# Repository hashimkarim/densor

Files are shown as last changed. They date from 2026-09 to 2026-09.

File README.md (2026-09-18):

# Densor



## About the project

Densor is an intraoral sensor platform, attached to regular dental retainers or aligners, that can take measurements inside the mouth. 

## Rationale

At present, in mouth measurements are typically made with external tools and in a controlled labaratory setting. Thus, real data from users daily lives is missing. To overcome this, we propose using widely used deltal retainers (or aligners), and enhance them with the Densor sensing platform. This way data is collected from inside the mouth without external tools. 

## Features

1. **Contactless transmission:** Densor is completely sealed and interacts with a smartphone via [NFC protocol](https://en.wikipedia.org/wiki/Near-field_communication). 
2. **Energy harvesting:** To stay powered Densor harvests energy, either from the [NFC communication itself](https://github.com/TUDSSL/densor/tree/master/NFC_harvester_battery_free) or from the [temperature gradient between the body and cold water](https://github.com/TUDSSL/densor/tree/master/TEG_harvester_battery_free). 
4. **Free of external hardware:** Operating Densor does not require any specialized tools, other than a NFC-compatible smartphone.

## Project layout

For the current NFC firmware (R2/R3 multirate logging), Android app, build
commands and protocol documentation, see the [software guide](NFC_harvester_battery_free/software/README.md).

This repository contains the design (both hardware and software) of two versions of Densor, based on the source of energy harvesting. Each version of the project is contained in its own folder:

1. **[Densor with NFC-based energy harvesting from a smartphone](https://github.com/TUDSSL/densor/tree/master/NFC_harvester_battery_free)**, as presented in [this research article](https://dl.acm.org/doi/10.1145/3699746);
2. **[Densor with thermoelectric energy harvesting from drinking cold water](https://github.com/TUDSSL/densor/tree/master/TEG_harvester_battery_free)**.

 

## Copyright

Copyright (C) 2024 TU Delft Embedded Systems Group/[Sustainable Systems Laboratory](https://github.com/TUDSSL).

MIT License or otherwise specified. See [license](https://github.com/TUDSSL/densor/blob/master/LICENSE.txt) file for details.

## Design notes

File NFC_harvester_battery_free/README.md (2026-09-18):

# Densor with NFC-based Energy Harvesting from a Smartphone

For the current R1/R2/R3 software, use the [firmware and Android guide](software/README.md).
The memory diagram and Time Sync/Charge operating steps below describe the
original published firmware. R2/R3 use independent sensor periods and the
Stop/Apply workflow documented in the current guide.



This is the official public repository for intraoral sensing platform, called Densor (a portmanteau of a word _dental_ and _sensor_), based on [NFC protocol](https://en.wikipedia.org/wiki/Near-field_communication) for energy harvesting and communication from a NFC-enabled smartphone. For a Densor version with thermoelectric energy harvesting from drinking cold water please refer to [this repository](https://github.com/TUDSSL/densor/tree/master/TEG_harvester_battery_free). 

## About the Project

This repository contains the design files of the NFC-based Densor:

- [Densor hardware](https://github.com/TUDSSL/densor/tree/master/NFC_harvester_battery_free/hardware)
- [Densor firmware](https://github.com/TUDSSL/densor/tree/master/NFC_harvester_battery_free/software/DentalSensor_StorageProject)
- [Android app](https://github.com/TUDSSL/densor/tree/master/NFC_harvester_battery_free/software/source_ST25NFCApplication_V3_9)
- [Experiment setup and data collected from Densor evaluation](https://github.com/TUDSSL/densor/tree/master/NFC_harvester_battery_free/data/experiments) presented in Densor's [accompanying publciation](https://dl.acm.org/doi/10.1145/3699746).

## Rationale behind Densor

Intraoral sensors are another type of sensors in the field of healthcare and technology. While head-worn wearables have made significant advancements in monitoring various health metrics, placing sensors directly in the mouth remains a challenge. Currently, we rely heavily on external tools to gather dental and oral health data, which leaves critical information missing. For those looking to deploy in-mouth sensors, the process is daunting, requiring them to start from scratch. Additionally, there is no straightforward way to keep these sensors small, safe, and capable of long-lasting communication, making it difficult to integrate them into practical applications.

## Challenges

Intraoral sensing is unique because it operates within one of the most dynamic and challenging environments in the human body—the mouth. Unlike other forms of wearable technology, intraoral sensors must contend with constant exposure to saliva, varying temperatures, and the mechanical forces of chewing and speaking. These sensors need to be not only highly sensitive and accurate but also biocompatible and safe for long-term use. Additionally, they offer the potential to gather real-time data on oral health, dietary habits, and even health conditions, providing insights that are difficult to obtain through external sensors. This makes intraoral sensing a powerful tool with unique capabilities that go beyond existing methods.

## Densor Architecture



### Communication and Data Storage

Densor uses the NFC interface (based on STMicroelectronics' [ST25DV64K](https://www.st.com/en/nfc/st25dv64k.html) NFC/RFID tag IC) for communication with a smartphone, and the on board non-voltatile memory to store measurements. This way, data collected by Densor is always available to be read out by the smartphone.

### Energy Harvesting

Energy is harvested from the NFC tag itself, and stored for later use. This allows for Densor's continous operation and reader-independent data collection.

### Energy Storage

The harvested energy is stored on capacitors instead of batteries. This makes Densor a battery-free device and thus safer and more acceptable than Densor based on batteries.

### Power Control

Despite using low-power sensors, energy would be drained from the storage capacitor(s) rapidly if Densor is kept continuously powered. As the harvested energy stored on the capacitors is limited, it is imperative that we save and expend this power carefully. To overcome this, we use a low power Real-Time Clock (RTC) [AB1805](https://abracon.com/Precisiontiming/AB18X5-RTC.pdf) with power switch for power management. This means that the microcontroller unit (MCU) and sensors are completely powered off in the inter-sample period, with only the RTC powered to determine wake up time. This method achieves better power saving than deep-sleep or any of the low power run modes of the MCU.

### Densor On-Board Sensors

As of now, Densor includes three sensing modalities: temperature, accelaration and light intensity. Measuring oral temperature, jaw position, and whether the mouth is open using intraoral sensors is useful for gaining insight into oral and overall health. Oral temperature sensors provide accurate readings to detect early signs of fever and inflammation. Jaw position sensors can monitor alignment and movement, making them valuable for detecting sleep patterns. Light sensors that detect whether the mouth is open can help track breathing patterns and oral habits, which are essential for identifying issues like mouth breathing or sleep-related disorders.

## Densor Operation



The above image shows examples of data collected by Densor and demonstrates its capabilities. The temperature can be seen rising to body temperature when Densor is inserted in the mouth. The light level falls when the mouth is closed, and rises when the mouth is open. It also varies when the user is speaking. When drinking cold water, the temperature initally falls and then rises back to body temperature.



Densor can also determine the orientation of the jaw when the head is tilted. This is particularly useful for measuring head position during sleep, as seen in the above figure. The figure shows actual data collected from a user during a full night's sleep with _one sample collected every two minutes_. We can see the orientation of the head change between left, right and center as the user changes their sleep position.

## Getting Started with Densor

The long-term goal of the Densor project is to lower the ceiling of development of intraoral sensors. Thus, we wish that everyone can build, use and even expand Densor to improve sensing capabilities and data collection. Here we explain the steps to create Densor from scratch.

### Building the Densor Hardware



The Densor printed circuit board (PCB) is built using off-the-shelf components and assembled onto a flexible PCB. In our case we have used the flex PCB services from [PCBway](https://www.pcbway.com/fpc-rigid-flex-pcb/flex-pcb.html). The picture above shows the main components of Densor ( (a comprehensive list of Densor hardware, along with links to buy them, can be found under [Hardware](https://github.com/TUDSSL/densor/tree/master/NFC_harvester_battery_free/hardware)).

- **A** Custom-designed PCB antenna
- **B** STMicroelectronics [ST25DV64K](https://www.st.com/en/nfc/st25dv64k.html) NFC tag
- **C** Seiko [CPH3225A](https://www.sii.co.jp/en/me/datasheets/chip-capacitor/cph3225a/) chip capacitor bank
- **D** Abracon [AB1805](https://abracon.com/Precisiontiming/AB18X5-RTC.pdf) RTC
- **E** STMicroelectronics [LIS2DW12](https://www.st.com/en/mems-and-sensors/lis2dw12.html) accelerometer
- **F** STMicroelectronics [STM32L021F4](https://www.st.com/en/microcontrollers-microprocessors/stm32l021f4.html) MCU
- **G** Vishay [VEMD1060X01](https://www.vishay.com/docs/84295/vemd1060x01.pdf) photodiode
- **H** Serial Wire Debug (SWD) programming port (which is cut off before embedding in a dental aligner).

The [Densor hardware](https://github.com/TUDSSL/densor/tree/master/NFC_harvester_battery_free/hardware) folder contains the [gerber files](https://github.com/TUDSSL/densor/tree/master/NFC_harvester_battery_free/hardware/gerbers_schematic) which can be used to order the PCBs directly. To order directly, use the `.gbr` Gerber output files and `.drl` drill file for manufacturing.



The hardware folder also contains Densor' [schematic](https://github.com/TUDSSL/densor/tree/master/NFC_harvester_battery_free/hardware/gerbers_schematic) and [KiCad](https://www.kicad.org/blog/2021/12/KiCad-6.0.0-Release/) project which can be used for further expansion or modifications of Densor. A screenshot of the Densor PCB design in KiCad can be seen above. To open the project using Kicad, launch Kicad and navigate to 'File' -> 'Open project' -> And choose the [`densor_nfc_v2.kicad_pro`](https://github.com/TUDSSL/densor/blob/master/NFC_harvester_battery_free/hardware/Densor_kicad_project/densor_nfc_v2.kicad_pro) project file. The project includes the KiCad project files `.kicad_pcb`, `.pro` and `.sch`.

With the PCB and components, we used the lead-free [SAC305](https://nl.mouser.com/datasheet/2/73/SMD291SNL250T3-595229.pdf) solder paste to assemble the Densor as per the schematic.

### Uploading the Firmware to Densor's MCU

Once the Densor hardware is assembled, the [STM32L021F4](https://www.st.com/en/microcontrollers-microprocessors/stm32l021f4.html) MCU on board the Densor needs to have the firmware uploaded. The Densor [software folder](https://github.com/TUDSSL/densor/tree/master/NFC_harvester_battery_free/software/DentalSensor_StorageProject) contains the [STM32CubeIDE](https://www.st.com/en/development-tools/stm32cubeide.html)-based project is required for this. The firmware is uploaded using a [J-Link Debug probe](https://www.segger.com/products/debug-probes/j-link/) and a 10-pin header.

_Note:_ The current version of the PCB also has an [5034800800 FPC connector](https://www.molex.com/en-us/products/part-detail/5034800800) with all SWD signals which can also be used for programming.

### Memory Layout and Pinout



### Using the Densor Smartphone App

With the firmware uploaded to the MCU, the Densor is ready to be uses. This can be verified with an Android-based smartphone running the Densor [smartphone app](https://github.com/TUDSSL/densor/tree/master/NFC_harvester_battery_free/software/source_ST25NFCApplication_V3_9). The app (screenshot below) is built using Android Studio and can interact with the assembled Densor PCB via NFC. Detailed instructions on how to build the app can be found [here](https://github.com/TUDSSL/densor/tree/master/NFC_harvester_battery_free/software/source_ST25NFCApplication_V3_9).



### Attaching Densor to Aligners using Epoxy

Finally, the Densor PCB has to be attached to the retiners or aligners. Clear plastic vaccum formed [retainers](https://en.wikipedia.org/wiki/Retainer_(orthodontics)) are widely used in orthodontic treatment. They can easily be fabricated with the help of a dental technician.

In our Densor fabrication process, first a [dental impression](https://en.wikipedia.org/wiki/Dental_impression) of each test subject was taken using [condensation silicone](https://products.coltene.com/EN/US/products/prosthetics/c-silicones/speedex/speedex-putty) placed on a dental impression tray. The hardened impression was later used to create a [plaster model](https://bredent-group.com/wp-content/uploads/2020/06/gipse-von-hoechster-Qualitaet_000727GB-20150601.pdf) of the subject's lower jaw teeth. Next, the plaster was placed inside an [Erkoform-3d+ dental  thermoforming unit](https://www.erkodent.de/en/product/?id=521210). Then, a dental [thermoforming plate](https://www.erkodent.de/wp-content/documents/products/thermoprosp_EN.pdf) was heated to 160 degrees Celcius by Erkoform-3d+, placed over the dental plaster and vacuum sealed. After vacuum sealing, all redundant and sharp edges of the fabricated aligner were removed by the cut-off wheel. The remaining imperfections were removed with the same cut-off wheel, and finally disinfected.

We used a [food safe epoxy](https://polyestershoppen.com/epoxy/voedselveilige-epoxy-419.html) to attach the assembled Densor PCB to the retainers. The epoxy has to be carefully mixed in a 10:6 ratio of resin and hardner, and applied over the PCB with a brush. The epoxy takes a _full five days to cure completely_ and must not be used before that even though it appears to have hardened.

**Once the epoxy is fully cured, Voila! You Densor is ready to use**.

## How to Operate Densor

To use Densor, begin with the smartphone app, and fully assembled Densor.

### Starting and Stopping Densor

_Step 1._ When you hold Densor close to the smartphone such that both NFC antennas of a Densor and a smartphone align, the app will launch automatically and Densor will begin charging.

_Step 2._ The capacitor's charged voltage will be displayed in the app. While Densor theoretically supports 3.3 V maximum capacitor voltage, in practice, it reaches about 2.6 V.

_Step 3._ To configure the on-board Densor sensors, go to the settings tab. Here, you can enable specific sensors, select the sampling rate, and set an optional delayed start. Click the `Update` button to apply these settings to the sensor.

_Step 4._ The Densor will only begin measuring once the time is synced. In the `Time Sync` tab, click the `Sync` button to start the sensor from the current time. The `Wipe` button deletes all previously collected data, while `Delete` resets the cursor without overwriting previous data with zeros.

_Step 5._ To stop the sensor, switch to `Charge` mode. This will revert the sensor to showing feedback on the charging voltage reached. _Note:_ This will also reset the timestamp. Please save measurements before putting Densor to charge mode.

### Reading the Data

_Step 1._ To save the data, go to the `Memory` tab and click `Dump memory to file`. In the 'Destination folder' field, enter your desired file name, then click `OK`. The data will be saved as a `.bin` file on your phone. The file is located in the 'Downloads' folder of the internal memory.

_Step 2._ To analyse this data, use the provided scripts avaible in the [data folder](https://github.com/TUDSSL/densor/tree/master/NFC_harvester_battery_free/data) of this repository.

_Step 3._ If the [experiment master](https://github.com/TUDSSL/densor/blob/master/NFC_harvester_battery_free/data/experiments/experiment_master_ui.py) script was used to generate the data as per a protocol, then place the generated `.bin` file in the [data dumps folder](https://github.com/TUDSSL/densor/tree/master/NFC_harvester_battery_free/data/experiments/data_dumps), and view the results with the [plot_labelled.py](https://github.com/TUDSSL/densor/blob/master/NFC_harvester_battery_free/data/experiments/plot_labeled.py) script. Make sure to use the [environment](https://github.com/TUDSSL/densor/blob/master/NFC_harvester_battery_free/data/environment.yml) provided.

## Collecting New Data

Data collected using Densor can be labelled and stored using the scripts in the [data folder](https://github.com/TUDSSL/densor/tree/master/NFC_harvester_battery_free/data/experiments).

1. **Using a predefined experiment protocol:** You can use a set of [existing experiment protocols](https://github.com/TUDSSL/densor/tree/master/NFC_harvester_battery_free/data/experiments/experiment_protocols) or create a new `.json` file to decide the tasks that will be performed while labeling data collected by Densor.
2. **Executing an experiment:** Run the [`experiment_master_ui.py`](https://github.com/TUDSSL/densor/blob/master/NFC_harvester_battery_free/data/experiments/experiment_master_ui.py) file to launch the instructing script. Perform the actions as instructed by the script for the prescribed duration.



3. **Save the data:** Save the data using the smartphone app with the name prompted by the script to a `.bin` file and place it in the [data_dumps](https://github.com/TUDSSL/densor/tree/master/NFC_harvester_battery_free/data/experiments/data_dumps) folder.
4. **Label and view the data:** Run the `data_labeller.py` script to label the data for further machine learning tasks, or `plot_labelled.py` file to view the data.

## Frequently Asked Questions

**1. How long does it take to charge Densor?**

It takes approximately a minute to charge Densor using a smartphone. The exact charging time depends on how well the antennas of Densor and the smartphone align. The exact charging voltage of the capacitors can be read on the app for feedback.

**2. How long does Densor run when fully charged?**

Densor's lifetime depends on the sampling rate and number of capacitors used. For example, when using two capacitors and sampling once every two minutes Densor lasts for about 7 hours on a single charge. To increase the lifetime, more capacitors can be added. This will however change the charging behavior as well.

**3. Is Densor comfortable to wear?**

In our opinion, the experience of using Densor is no different than using retainers. Thus, if using retainers/aligners anyway, Densor should cause no additional discomfort beyond usinh the retainer.

**4. Will the mouth opening detection based on light intensity work when sleeping in the dark?**

Unfortunately, the mouth opening detection only works when there is sufficient ambient light. We are investigating ways to increase sensitivity for dark environments.

**5. Can I buy a Densor?**

Densor can be built with the design files in _this repository_. We desire Densor to be a free open source platform that can be rebuilt and expanded by everyone. If you wish to use (or expand) for your own research, please do not hesitate to contact us. We are happy to assist in reproduction efforts.

## How to Contribute to this Project

We look forward to your contributions, improvements, additions and changes. Please follow the standard [GitHub flow](https://docs.github.com/en/free-pro-team@latest/github/collaborating-with-issues-and-pull-requests/github-flow) for code contributions. In macro terms this means the following.

1. [Fork the `master` branch](https://docs.github.com/en/free-pro-team@latest/github/getting-started-with-github/fork-a-repo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)  of this repository; make sure that your fork will be [up to date](https://docs.github.com/en/free-pro-team@latest/github/getting-started-with-github/fork-a-repo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) with the latest `master` branch.
1. Create an issue [here](https://github.com/TUDSSL/densor/issues) with a new feature or a bug report.
1. Perform changes on your local branch and [push them to your forked clone](https://docs.github.com/en/free-pro-team@latest/github/collaborating-with-issues-and-pull-requests/merging-an-upstream-repository-into-your-fork).
1. Create a [pull request](https://docs.github.com/en/free-pro-team@latest/github/collaborating-with-issues-and-pull-requests/creating-a-pull-request) referencing the issue it covers and wait for our response.

### List of Known Issues

List of all known issues is listed in the [Issues](https://github.com/TUDSSL/densor/issues) list of this project. If you found a bug or you would like to enhance Densor with new functionalities: [please contribute](#How-to-Contribute-to-this-Project)! We look forward to your additions.

## How to Cite This Work

The results of this project have been published in a peer-reviewed academic publication (from which certain technical figures and text in this file originate). Details of the publication are as follows.

* **Authors and the project team:** [Vivian Dsouza](https://www.linkedin.com/in/dsouzavivian), [Jeffrey Pronk](https://www.linkedin.com/in/jeffrey-p-ba3225332), [Christian Peppelman](https://www.linkedin.com/in/peppelmanc), [Víctor Ignacio Madariaga](https://www.linkedin.com/in/vignaciomr), [Tatiana Pereira-Cenci](https://www.linkedin.com/in/tatiana-pereira-cenci-78813118/), [Bas Loomans](https://www.linkedin.com/in/bas-loomans-370ba11/), [Przemysław Pawełczak](http://www.pawelczak.net/)
* **Publication title:** _Densor: An Intraoral Battery-Free Sensing Platform_
* **Pulication venue:** [Proceedings of the ACM on Interactive, Mobile, Wearable and Ubiquitous Technologies, Volume 8, Issue 4, November 2024](https://dl.acm.org/toc/imwut/2024/8/4)
* **Link to publication:** https://dl.acm.org/doi/10.1145/3699746 (Open Access)

To cite this publication please use the following BiBTeX entry.

```
@article{dsouza:imwut:2024:densor,
  title = {Densor: An Intraoral Battery-Free Sensing Platform},
  author = {Vivian {Dsouza} and Jeffrey {Pronk} and Christian {Peppelman} and V\'{i}ctor Ignacio {Madariaga} and Tatiana {Pereira-Cenci} and Bas {Loomans} and Przemys{\l}aw {Pawe{\l}czak}},
  journal = {Proc. ACM Interact. Mob. Wearable Ubiquitous Technol.},
  volume = {8},
  number = {4},
  pages = {191:1--191:30},
  year = {2024},
  publisher = {ACM}
}
```

## Acknowledgements

We thank [Tofik Babayev](https://www.linkedin.com/in/tofik-babayev-36aa561a0) from [TofDent](https://www.tofdent.nl), The Hague, The Netherlands, for help in fabricating all versions of the Densor. We also thank [Giuseppe Deininger](https://www.linkedin.com/in/giuseppe-deininger-564a40153) and [Jakub Patałuch](https://www.linkedin.com/in/jakubpat) for contribution to the development of Densor at the initial states of the development. We also thank [Lennart Klaver](https://www.linkedin.com/in/lennart-klaver-19010945) for first attempts in designing intraoral sensor hardware, [Jasper de Winkel](https://www.linkedin.com/in/jdewinkel) for system design consulting and [Izabela Grudzińska](https://www.linkedin.com/in/grudzinskaizabela) for dentistry consulting and for the inspiration of this project. The study was partly funded by the [ORANGE-FORCE](https://www.nivel.nl/nl/project/orange-force-mond-en-tandheelkundige-zorg-voor-ouderen) project co-funded by the [PPP allowance](https://www.health-holland.com/public-private-partnerships) made available by [Health Holland](https://www.health-holland.com), [Top Sector Life Sciences and Health](https://www.academictransfer.com/en/employer/Health-Holland/).

 

## Copyright

Copyright (C) 2024 TU Delft Embedded Systems Group/[Sustainable Systems Laboratory](https://github.com/TUDSSL).

MIT License or otherwise specified. See [license](https://github.com/TUDSSL/densor/blob/master/LICENSE.txt) file for details.

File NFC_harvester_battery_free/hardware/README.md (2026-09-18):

# Densor - Hardware

The TMP119 and its 100 nF capacitor sit **14.5 mm beyond the original PCB edge**.
R2/R3 remain **100 kΩ**, C14 connects `V_MCU` to `PSW`, and ALERT is unconnected.
The neck enforces 0.15 mm tracks for `V_MCU`/SDA/SCL and 0.20 mm for `PSW`,
with no vias/components; the continuous back GND fill and repaired GND connection remain.

[Current schematic](gerbers_schematic/schematic_nfc_baterry_free_fpc.pdf) ·
[Gerbers and drills](gerbers_schematic/gerbers_fpc) ·
[PCB layout](exports/pcb.pdf) · [3D render](exports/3d-oblique.png) ·
[BOM](exports/bom.csv) · [Placements](exports/placement.csv)

The original CAD stackup is retained, including its recorded **1.6 mm** thickness.
`exports/densor_nfc_v2.step` contains the native stackup and components;
`exports/board-1.6mm.step` is the nominal board envelope. Actual flex construction
and bend radius are unspecified in the original. Model sources and licenses are in
`Densor_kicad_project/vendor/`.

Latest checks: zero unrouted connections and no new DRC/ERC/parity findings.
The 31 DRC, 19 ERC and 20 metadata findings are inherited. Final I²C, wake/sleep
and bent/epoxied fit measurements across 2.6–1.8 V remain pending.
The purchasing links below are historical; use the schematic BOM for current
values, and complete its missing MPN fields before ordering.

## About the project 

This repository contains the design of Densor: an intraoral, actively powered, battery-free platform featuring multi-modal sensors and an extended lifespan. The repository consists of all components that make Densor:
- [Hardware](https://github.com/TUDSSL/densor/tree/master/NFC_harvester_battery_free/hardware)
- [Densor Firmware](https://github.com/TUDSSL/densor/tree/master/NFC_harvester_battery_free/software/DentalSensor_StorageProject)
- [Android app](https://github.com/TUDSSL/densor/tree/master/NFC_harvester_battery_free/software/source_ST25NFCApplication_V3_9)
- [Experiment setup and data collected](https://github.com/TUDSSL/densor/tree/master/NFC_harvester_battery_free/data/experiments)

This folder contains all the harware design files.

## Folder layout

- [KiCad project](Densor_kicad_project/densor_nfc_v2.kicad_pro): current design, local symbols, footprints and all 25 component STEP models.
- [Datasheets](datasheets): component reference PDFs.
- [Gerbers and schematic](gerbers_schematic): current extension Gerbers, drills, job file and schematic PDF.
- [Exports](exports): PCB views, renders, assembly drawings, BOM, placements and STEP files.

## Historical baseline purchasing references

| Component | Qty | Purchased from |
|---|-----|---|
| Storage Capacitor | 2 | [link to buy](https://www.digikey.com/en/products/detail/seiko-instruments/CPH3225A/8692444) |
| Decoupling Capacitor 100nF | 6 | [link to buy](https://nl.farnell.com/en-NL/kemet/c0603x104m4ractu/cap-mlcc-0-1uf-16v-0603/dp/2904941?st=0603%200.1uf) |
| Zener Diode | 1 | [link to buy](https://nl.farnell.com/on-semiconductor/mm3z3v6c/zener-diode-0-2w-3-6v-sod-323f/dp/2824925?CMP=i-ddd7-00001003) |
| Schottky Diode | 1 | [link to buy](https://nl.farnell.com/nexperia/1ps76sb40-115/diode-schottky-sod323/dp/1349646?CMP=i-ddd7-00001003) |
| Photo Diode | 1 | [link to buy](https://nl.mouser.com/ProductDetail/Vishay-Semiconductors/VEMD1060X01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) |
| Debug header | 1 | [link to buy](https://nl.farnell.com/samtec/ftsh-105-01-l-d-k/connector-header-10pos-2row-1/dp/2856435?CMP=i-ddd7-00001003) |
| FPC connector | 1 | [link to buy](https://nl.mouser.com/ProductDetail/Molex/503480-0800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) |
| Pin Header 01x04 | 1 | [link to buy](https://nl.mouser.com/ProductDetail/Harwin/M20-9770446?qs=ulE8k0yEMYbCPpMPHeYh4w%3D%3D) |
| Resistor 100kohm | 3 | [link to buy](https://nl.farnell.com/vishay/crcw0603100kfkea/res-100k-1-0-1w-0603-thick-film/dp/1469649?st=0603%20100k) |
| Resistor 8Mohm | 1 | [link to buy](https://nl.farnell.com/vishay/crcw06038m06fkea/res-8m06-1-0-1w-0603-thick-film/dp/2138717) |
| NFC Tag - ST25DV04K-JFR6D3 | 1 | [link to buy](https://www.digikey.nl/en/products/detail/stmicroelectronics/ST25DV64K-JFR6D3/7312974) |
| RTC - AM1805 | 1 | [link to buy](https://nl.farnell.com/en-NL/abracon/ab1805-t3/real-time-clock-i2c-qfn-16/dp/2467703?st=ab1805) |
| MCU - STM32L021F3Ux | 1 | [link to buy](https://www.digikey.nl/en/products/detail/stmicroelectronics/STM32L021F4U6TR/6166967) |
| Accelerometer - LIS2DW12 | 1 | [link to buy](https://nl.farnell.com/en-NL/stmicroelectronics/lis2dw12tr/lga-12-i-mems-digital-o-p-motion/dp/2849615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) |
| SPDT - TS3A44159 | 1 | [link to buy](https://www.digikey.nl/en/products/detail/texas-instruments/TS3A44159RSVR/1909585) |
| Crystal | 1 | [link to buy](https://nl.farnell.com/en-NL/abracon/abs05w-32-768khz-j-2-t/crystal-32-768khz-4pf-smd-1-6/dp/2850126?st=abs05w) |
| Solder paste | - | [link to buy](https://www.digikey.nl/en/products/detail/chip-quik-inc/SMD291SNL50T3/5130160) |

## Copyright

 

Copyright (C) 2024 TU Delft Embedded Systems Group/Sustainable Systems Laboratory.

MIT Licence or otherwise specified. See [license](https://github.com/TUDSSL/ENGAGE/blob/master/LICENSE) file for details.

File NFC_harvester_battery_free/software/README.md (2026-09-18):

# Densor firmware and Android software

The current firmware implements independent sensor periods with two storage
layouts and two schedulers. R2 uses a shared EEPROM pool; R3 uses per-sensor
partitions. Suffix **a** selects a retained finite-state machine (FSM), and
suffix **b** selects RTC-time scheduling. All four use protocol version 5.
They are software-tested candidates; physical timing, energy and power-loss
validation remain pending.

| Revision | Storage | Scheduler | Build selector |
| --- | --- | --- | --- |
| R2a | Shared pool | Retained FSM | `REVISION=R2a` |
| R2b | Shared pool | RTC time | `REVISION=R2b` |
| R3a | Per-sensor partitions | Retained FSM | `REVISION=R3a` |
| R3b | Per-sensor partitions | RTC time | `REVISION=R3b` |

The Makefile defaults to **R3a**. Storage and scheduler are selected when
building firmware; the Android app detects them and cannot switch them.
One current app supports legacy recordings, R1, and all four R2/R3 variants.

- [Implementation and operation](docs/multirate-implementation.md): scheduling,
  storage, migration, configuration and recovery.
- [Protocol version 5](docs/multirate-protocol.md): EEPROM map, records,
  requests and retained state.
- [Validation and limitations](docs/multirate-validation.md): checks run against
  this checkout and remaining hardware work.
- [R1 reference](docs/r1-software.md) and [R1 protocol v3](docs/r1-protocol.md):
  historical common-period logging and compatibility details.

## Build and check

From the repository root, with GNU Make, Python 3 and the
`arm-none-eabi-gcc` toolchain on `PATH`:

```sh
make -C NFC_harvester_battery_free/software/DentalSensor_StorageProject -j4 REVISION=R2a
make -C NFC_harvester_battery_free/software/DentalSensor_StorageProject -j4 REVISION=R2b
make -C NFC_harvester_battery_free/software/DentalSensor_StorageProject -j4 REVISION=R3a
make -C NFC_harvester_battery_free/software/DentalSensor_StorageProject -j4 REVISION=R3b
```

Each variant has its own directory under
`DentalSensor_StorageProject/build/<storage>-<timing>/`, containing
`densor-<revision>-<storage>-<timing>.elf`, `.bin`, `.hex`, `.map` and
`-manifest.json`. For example, R2b produces
`build/shared-rtc/densor-r2b-shared-rtc.elf`. Compiler flags and stack-usage
reports are also retained. Switching variants does not require cleaning.
The equivalent selectors are `STORAGE=shared|partitioned` and `TIMING=fsm|rtc`;
conflicting revision/strategy choices fail.

Host checks additionally require Clang with address/undefined-behavior sanitizer
runtimes, `javac` and `java`:

```sh
python3 NFC_harvester_battery_free/software/tools/test_r1.py
python3 NFC_harvester_battery_free/software/tools/test_multirate.py
```

To package all four variants and the matching Android app, set `JAVA_HOME` to
JDK 17 and `ANDROID_HOME` to an SDK with Android 33, build-tools 35.0.0,
platform-tools and accepted licenses, then run:

```sh
python3 NFC_harvester_battery_free/software/tools/build_multirate.py
```

The helper also accepts `--java-home` and `--sdk`. It creates a scoped SDK view,
checks build selections, runs both host suites, and builds/tests the Android
variants. Output is in `software/build/multirate-candidate/`: firmware images,
the release APK, manifests, checksums and build/test logs. This command builds
an unpublished candidate; it does not install or flash a device.

The app identifies as `com.st.st25nfc`, version `3.11.0-multirate`, code 29,
minimum API 23 and target API 33. It retains the project's local debug signing
configuration. A successful build does not establish compatibility with a
previously deployed signing key or release readiness.

`build_r1.py` is historical: it expects R1 artifact paths and APK version 28.
The current Makefile has no `REVISION=R1` target; use `test_r1.py` to check the
retained R1 implementation and decoder.

## Start a recording

1. Save the existing EEPROM dump, build the selected revision, and follow the
   [SWD migration procedure](docs/multirate-implementation.md#migration-and-provisioning).
2. In the app, read the detected revision and state. For a running R2/R3 session,
   select **Stop and checkpoint recording**, refresh after a device wake, and
   wait for acknowledgement before exporting the final recording.
3. Select sensors, a base period and each enabled sensor's period. Periods are
   whole multiples of the base. For example, base 10 s with LIS2DW12 temperature,
   TMP119, photodiode and acceleration periods of 120/60/30/10 s gives
   multipliers 12/6/3/1. Startup delay is 0–59 minutes.
4. Select **Apply settings and reset log**. This replaces the previous session
   once the MCU accepts it. Pending settings remain distinct from active ones.
5. Read binary/CSV snapshots in Data, or Stop and await acknowledgement for a
   completed recording. Times are elapsed seconds; UTC is unavailable.

R1 uses its own apply/reset workflow without a Stop command. The original
firmware's Time Sync/Charge workflow does not apply to R1/R2/R3.

## Work without a board

Build `:app:assembleDebug` from
[`source_ST25NFCApplication_V3_9`](source_ST25NFCApplication_V3_9), open
**ST25 dbg → Debug mode**, and select a sample or import a raw EEPROM `.bin`.
The debug package `com.st.st25nfc.dbg` can coexist with the release app.
R2/R3 imports require the complete 512-, 2048- or 8192-byte EEPROM image.
Virtual memory supports decoding, settings requests and export; it does not
simulate firmware acknowledgements, acquisition or time progression.

The [Sampling lab](../visualization/sampling_lab/README.md) exports synthetic
R1/R2a/R2b/R3a/R3b EEPROM images. The
[EEPROM lab](../visualization/eeprom_lab/README.md) compares memory layouts.
These are test and visualization tools; synthetic rates do not establish
physical firmware sampling performance.

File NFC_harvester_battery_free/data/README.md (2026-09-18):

# Densor - Data 

## About the project 

This repository contains the design of Densor: an intraoral, actively powered, battery-free platform featuring multi-modal sensors and an extended lifespan. The repository consists of all components that make Densor:
- [Hardware](https://github.com/TUDSSL/densor/tree/master/NFC_harvester_battery_free/hardware)
- [Densor Firmware](https://github.com/TUDSSL/densor/tree/master/NFC_harvester_battery_free/software/DentalSensor_StorageProject)
- [Android app](https://github.com/TUDSSL/densor/tree/master/NFC_harvester_battery_free/software/source_ST25NFCApplication_V3_9)
- [Experiment setup and data collected](https://github.com/TUDSSL/densor/tree/master/NFC_harvester_battery_free/data/experiments)

This folder contains all the scripts to collect, process and analyse the data using Densor, as well as the data collected itself.

## Folder layout

- [Synthetic multirate dataset](synthetic_multirate/README.md): simulated acceleration, light, and two temperature channels at 100 Hz, with noise-free curves and event labels for sampling comparisons.

- [Charging:](https://github.com/TUDSSL/densor/tree/master/NFC_harvester_battery_free/data/charging)  contains the data traces of how densor charges with a smartphone. 
- [Earpiece:](https://github.com/TUDSSL/densor/tree/master/NFC_harvester_battery_free/data/earpiece) contains the scripts used to collect data from the ear piece for the experiments that compare Densor to a similar earable platform.
- [Experiments:](https://github.com/TUDSSL/densor/tree/master/NFC_harvester_battery_free/data/experiments) contains all scripts and data used for the machine learning experiments.
- [Retainer:](https://github.com/TUDSSL/densor/tree/master/NFC_harvester_battery_free/data/retainer) contains all scripts and data collected from the Densor that are not related to the machine learning experiments.

## Setting Up the Environment

To set up the Conda environment from the provided `.yml` file, follow these steps:

### 1. Ensure Conda is Installed

Make sure you have Conda installed on your system. If you don't have it installed, you can download and install it from the [official Anaconda website](https://www.anaconda.com/products/distribution) or by using [Miniconda](https://docs.conda.io/en/latest/miniconda.html) for a lighter version.

### 2. Clone the Repository

Clone this repository to your local machine if you haven't done so already:

```bash
git clone https://github.com/TUDSSL/densor.git
cd densor
```

### 3. Create the Environment from the .yml File

Use the following command to create a new environment from the environment.yml file:

```bash
conda env create -f environment.yml
```

### 4. Activating the environment

Use the following command to activate the environment:

```bash
conda activate densor
```

## Description of how figures in the paper were produced

1. **Figure 5: Charging characteristics:** Run the `plot_charging_traces.py' script

```bash
cd NFC_harvester_battery_free/data/charging/
python3 plot_charging_traces.py
```   

2. **Figure 6 (a,b,c): Power and Lifetime** Run the `math_model_life.py' script

Set the below variables to True, based on the desired output
```
PLOT_CAPS = True
PLOT_CURRENT = False
PLOT_START_VOLTAGE = False
```

```bash
cd NFC_harvester_battery_free/data/charging/
python3 math_model_life.py
```   

3. **Figure 7: Example data from all sensors** Run the `plot_pretty_manually.py` script

```bash
cd NFC_harvester_battery_free/data/retainer/
python3 plot_pretty_manually.py
```
4. **Figure 10: Distribution of temperature and light intensity** Run the `data_ml.py` script with variable `plot_box_plots = True`
   
```bash
cd NFC_harvester_battery_free/data/experiments
python3 data_ml.py
```
5. **Figure 11 (a,b,c): Data from Densor and Earable** Run the `plot_ear_mouth_example_trace.py' script with arguments as explained [here](https://github.com/TUDSSL/densor/tree/master/NFC_harvester_battery_free/data/experiments).
6. **Figure 12: ROC** Run the `data_ml.py` script with variable `plot_roc_curve = True`

```bash
cd NFC_harvester_battery_free/data/experiments
python3 data_ml.py
```
7. **Figure 13: Example data from sleep** Run the `plot_pretty_sleep_manually.py` script

```bash
cd NFC_harvester_battery_free/data/retainer/
python3 plot_pretty_sleep_manually.py
```

## Copyright

 

Copyright (C) 2024 TU Delft Embedded Systems Group/Sustainable Systems Laboratory.

MIT Licence or otherwise specified. See [license](https://github.com/TUDSSL/ENGAGE/blob/master/LICENSE) file for details.

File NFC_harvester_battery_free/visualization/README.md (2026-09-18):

# Densor visualization labs

Local browser tools for exploring Densor sampling and EEPROM storage.

| Lab | Purpose | Default port | Requirements |
| --- | --- | --- | --- |
| [Sampling lab](sampling_lab/README.md) | Explore sensor rates and export synthetic recordings. | 8765 | Bash and Python 3.10+ |
| [EEPROM lab](eeprom_lab/README.md) | Compare memory layouts and page crossings; vary payloads and add sensors. | 8767 | Bash, Node.js 22.18+ and npm |

From the repository root, start either lab:

```sh
./NFC_harvester_battery_free/visualization/sampling_lab/run.sh
./NFC_harvester_battery_free/visualization/eeprom_lab/run.sh
```

Each script also works from inside its lab folder as `./run.sh [port]`, or by
absolute path from any directory. For example, `./run.sh 9000` starts at port
9000. Without an argument, it starts at the default above. If the port is busy,
it tries successive ports until it can bind, then prints the URL and opens it
in your default browser. Valid ports are 1–65535. On a headless machine, open
the printed URL manually. Stop the server with Ctrl+C.

Both servers bind to `127.0.0.1`. The EEPROM launcher installs its locked npm
dependencies on first run if they are missing (requires network access).
The sampling lab reads the existing
[synthetic dataset](../data/synthetic_multirate/README.md); generate it first if
it is missing. Each lab's README describes its features and validation commands.

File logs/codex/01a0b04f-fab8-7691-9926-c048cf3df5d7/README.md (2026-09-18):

# Summary

This conversation was used to create synethic data. I want to do implement multirate sampling in both the firmware and the android app. This high frequency (100Hz) allows me to make data dumps for testing at will.

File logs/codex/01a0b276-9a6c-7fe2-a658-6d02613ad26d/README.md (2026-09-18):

# Summary

This conversation was used to add all the 3D models to KiCAD and export all the resulting files/renders/pdfs.

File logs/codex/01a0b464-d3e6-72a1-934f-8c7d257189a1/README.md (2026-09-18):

# Summary

This conversation was used to document the R1 firmware changes, including temperature-sensor selection, EEPROM alignment, data formats, build instructions and testing. It also updated the implementation handoff for one firmware codebase with separate storage and timing modules. The Android app was extended to detect and support R1, R2 (shared pool) and R3 (partitions), including both FSM and RTC timing variants for R2/R3 and import of synthetic EEPROM `.bin` dumps. The debug workflow was tested using Android Agent Lab and the Samsung S21 FE, including settings changes, read-back and dump import/export; physical sampling timing and NFC hardware behavior still require a Densor board.

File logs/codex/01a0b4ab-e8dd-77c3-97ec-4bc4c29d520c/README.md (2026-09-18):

# Summary

This conversation was used to add a debug mode to the Android app so I could test sampling-interval settings without a Densor board. It supports importing EEPROM `.bin` dumps, changing settings in simulated tag memory, verifying them by reading them back, and exporting and reopening the modified dumps. The workflow was tested on the Samsung S21 FE and 13 automated tests passed; actual sensor sampling timing still requires a Densor board.

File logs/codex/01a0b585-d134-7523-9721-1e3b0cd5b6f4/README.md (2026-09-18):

# Summary

This conversation documented the current R2a/R2b shared-pool and R3a/R3b
partitioned firmware, including FSM/RTC scheduling, protocol v5, build selection,
SWD migration, Stop/Apply operation, data exports and recovery limits. The old
software README was retained as a historical R1 reference and repository entry
points now link to the current guides.

All four incremental firmware build targets and both host test suites passed.
Hardware validation remains pending. See [conversation](conversation.md) and
[verification record](qa/verification.json). No firmware code was changed.

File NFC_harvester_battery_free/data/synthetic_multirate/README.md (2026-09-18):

# Synthetic multirate sampling dataset

A reproducible, simulated recording to replay as the input to a sampling
experiment. It contains **one three-axis accelerometer, one light sensor, and
two temperature sensors**: six measurement channels. These are synthetic
signals, not measurements from a person or calibrated Densor hardware.

The supplied recording lasts **30 minutes at 100 Hz** (180,000 rows). Each row
represents an instantaneous observation, 10 ms after the previous one. The
last timestamp is 1799.99 s; the recording interval is `[0, 1800)`.

## Files

- [dataset/samples.csv](dataset/samples.csv): noisy measurements for the scanner.
- [dataset/ground_truth.csv](dataset/ground_truth.csv): matching noise-free
  curves, for evaluation only. Both temperature columns are identical here.
- [dataset/events.csv](dataset/events.csv): event labels and parameters, for
  evaluation only. Intervals include their start and exclude their end.
- [dataset/metadata.json](dataset/metadata.json): seed, units, model assumptions,
  sources, and file checksums.
- [dataset/validation.json](dataset/validation.json): generated-data checks and
  measured noise statistics.
- [dataset/overview.png](dataset/overview.png): whole recording.
- [dataset/detail.png](dataset/detail.png): close-ups of jaw motion and the
  small difference between the temperature channels.

## Columns and noise

| Column | Meaning | Independent Gaussian noise, standard deviation |
|---|---|---:|
| `time_s` | Elapsed time in seconds | None |
| `accel_x_g` | X acceleration, including gravity, in g | 0.0020 g |
| `accel_y_g` | Y acceleration, including gravity, in g | 0.0024 g |
| `accel_z_g` | Z acceleration, including gravity, in g | 0.0022 g |
| `light_norm` | Normalized light intensity, 0–1 | 0.0030 |
| `temp_1_c` | Temperature sensor 1, degrees Celsius | 0.015 °C |
| `temp_2_c` | Temperature sensor 2, degrees Celsius | 0.020 °C |

The temperature sensors have the **same underlying temperature, response, and
calibration**. Only their independent noise differs. These noise levels are
chosen simulation parameters, not measured sensor specifications. Light is
dimensionless and is not a lux measurement or the Densor ADC output.

The six measurement channels have independent noise streams. Event generation
uses a separate stream, so changing the noise cannot move the events.

## Events and assumptions

The default schedule has 8 rhythmic jaw-movement bouts, 5 speaking bouts,
4 mouth-open intervals, 3 cool-drink events, and 5 posture transitions.
Onsets are randomized without consulting the 120-second sampling grid.
The first 30 seconds contain no activity events and can be used to inspect
noise and slow baseline variation.

- **Posture:** smooth changes to roll and pitch rotate the 1 g gravity vector.
  The new posture persists after the transition. The event interval labels
  the transition, not the entire subsequent held posture.
- **Rhythmic jaw movement:** smoothly enveloped 0.5–1.5 Hz motion, with a small
  second harmonic and different projections onto the three axes. These bouts
  do not force the mouth open or produce a light signal.
- **Speaking:** irregular light fluctuations and smaller jaw movements during
  the same labeled interval. Illumination is assumed sufficient.
- **Mouth opening:** a sustained light increase and small pitch change, with
  smoothed opening and closing edges.
- **Drinking:** a light/opening transient and a smooth temperature decrease,
  followed by recovery. Temperature recovery continues after drinking ends.
  `end_s` labels the drinking action; `response_end_s` marks the observed end
  of the modeled thermal response. Recovery is smoothly tapered to zero
  between five and six time constants.
- **Temperature baseline:** slow variation around 36.4 °C. Both temperature
  channels receive exactly the same baseline and drink response.

The jaw rhythm range is motivated by Martinot et al. (2021), who report
0.5–1.5 Hz mandibular movements in phasic sleep bruxism:
<https://pmc.ncbi.nlm.nih.gov/articles/PMC8397703/>.
Their chin-mounted inertial system differs from Densor. Chun et al. (2020)
demonstrate intraoral acceleration sensing at 54 Hz with four-second analysis
windows: <https://doi.org/10.1145/3410531.3414309>.
The Densor paper motivates the light/speaking and temperature/drinking
relationships: <https://doi.org/10.1145/3699746>.

Event durations, amplitudes, occurrence counts, noise levels, temperature
recovery constants, and 100 Hz reference rate are **simulation choices**.
The recording combines illustrative activities and is not a clinical sleep
recording, a validated physiological model, or evidence of detection accuracy.

## Scan or replay

The scanner should receive only `samples.csv`. At replay time `t`, expose the
newest row with `time_s <= t`. For real-time playback, release rows every
10 ms; for accelerated playback, advance the same simulation clock faster.
Use elapsed timestamps to determine availability rather than relying on the
precision of operating-system sleep calls.

For a sampler starting at zero, the suggested fixed rates align exactly with
the reference grid:

| Sampler | Rows selected, counting the first data row as index 0 |
|---|---|
| Original, all sensors every 120 s | 0, 12000, 24000, … |
| Accelerometer, 25 Hz | 0, 4, 8, …; read all three axes together |
| Light, 1 Hz | 0, 100, 200, … |
| Both temperatures, 0.1 Hz | 0, 1000, 2000, … |

These are point samples. Do not average the rows between observations unless
that is the acquisition behavior being evaluated. A held/interpolated output
is not an additional measurement. A 100 Hz reference is a discrete surrogate
for a continuous signal; it does not model unobserved content above 50 Hz,
sensor filtering, quantization, startup delay, energy, or storage constraints.

Keep `ground_truth.csv` and `events.csv` out of the scanner; use them afterward
to score detection and reconstruction. Repeat with multiple seeds and sampling
phases before drawing conclusions. The optional multirate settings here are
comparison settings, not validated optimal rates or a firmware implementation.

## Regenerate

With Python 3.11 or newer, from this directory:

```bash
python -m pip install -r requirements.txt
python generate.py
```

The default output is `dataset/` next to the generator. To make a separate
recording without overwriting the supplied one:

```bash
python generate.py --seed 42 --output /tmp/densor-synthetic-42
```

`--duration-s` (minimum 300 s) and `--rate-hz` (minimum 50 Hz) are configurable.
The seed defaults to 20260918. Identical parameters and NumPy version reproduce
the CSV files byte for byte. `validation.json` includes serialization,
temperature-noise independence, and event/quiet-region checks.

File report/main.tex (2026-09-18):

% Based on the supplied article template, with a compact report layout.
\documentclass[a4paper]{article}
\usepackage[a4paper,margin=15mm]{geometry}
\usepackage[T1]{fontenc}
\usepackage[default]{sourcesans}
\pdfmapfile{=SourceSansThree.map}
\usepackage{microtype}
\usepackage{graphicx}
\usepackage{xcolor}
\usepackage{titlesec}
\definecolor{ink}{HTML}{182535}
\definecolor{muted}{HTML}{526171}
\definecolor{linkblue}{HTML}{0866C6}
\definecolor{rulegray}{HTML}{D8E0E8}
\usepackage[colorlinks=true,allcolors=linkblue]{hyperref}
\pagestyle{empty}
\setlength{\parindent}{0pt}
\setlength{\parskip}{2pt}
\setlength{\emergencystretch}{2em}
\titleformat{\section}{\color{ink}\bfseries\fontsize{11.5}{13.5}\selectfont}{}{0pt}{}
\titlespacing*{\section}{0pt}{7pt}{3pt}
\hypersetup{
  pdftitle={PhD Assignment Report},
  pdfauthor={Hashim Karim},
  pdfsubject={Temperature sensor selection, placement, integration and firmware improvements}
}

\begin{document}
\color{ink}
\fontsize{10.2}{12.2}\selectfont
\begin{minipage}[t]{0.60\linewidth}
\vspace{0pt}
{\fontsize{25}{28}\selectfont\bfseries PhD Assignment Report\par}
\end{minipage}\hfill
\begin{minipage}[t]{0.38\linewidth}
\vspace{0pt}
\raggedleft
{\fontsize{11}{13}\selectfont\bfseries Hashim Karim\par}
{\fontsize{9.3}{12}\selectfont
\href{mailto:h.karim-2@student.tudelft.nl}{h.karim-2@student.tudelft.nl}\\
\href{https://github.com/hashimkarim/densor}{github.com/hashimkarim/densor}\par}
\end{minipage}
\par\vspace{5pt}
{\color{linkblue}\hrule height 0.8pt}
\vspace{2pt}

\section*{Approach}
I extended Densor with external temperature sensing and independent sampling
rates. Revision 1 (R1) corrects baseline logging; Revision 2 (R2) and
Revision 3 (R3) introduce shared and partitioned multirate storage, respectively.

\section*{Sensor selection}
I considered an NTC thermistor, MAX30208, TMP117 and TMP119 for the 2.6--1.8~V
supply, prioritizing energy per reading. An NTC would require an accuracy budget
covering the thermistor, reference resistor and ADC, and possibly calibration.
\href{https://www.analog.com/media/en/technical-documentation/data-sheets/max30208.pdf\#page=8}{MAX30208}
offered lower conversion current, but its longer possible result latency could
extend the device's active time. I chose \textbf{TMP119} for factory-calibrated
I\textsuperscript{2}C readings, conversion energy similar to TMP117, tighter
specified accuracy and better tolerance to assembly and bending stress.
Professional assembly made its small package practical.

\par\vspace{5pt}
\begin{minipage}[t]{0.53\linewidth}
\vspace{0pt}
\section*{Sensor placement}
I placed TMP119 14.5~mm beyond the original board edge, with its 100~nF decoupling
capacitor nearby. The extension is intended to allow placement farther back in
the mouth, away from the main electronics. Literature examples favoured posterior
sites for reduced airflow effects
(\href{https://doi.org/10.1038/s41405-022-00114-8}{de Almeida e Bueno et al., 2022})
and greater temperature stability
(\href{https://doi.org/10.1016/j.rineng.2025.105284}{Zhao and Bergmann, 2025}).
\end{minipage}\hfill
\begin{minipage}[t]{0.44\linewidth}
\vspace{0pt}
\centering
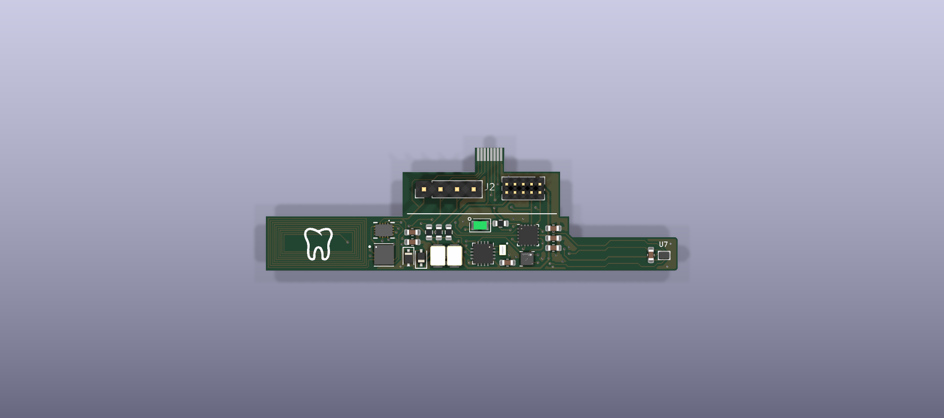
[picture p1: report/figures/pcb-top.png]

\par\vspace{3pt}
{\fontsize{8.5}{10}\selectfont\color{muted} Top-view PCB render. TMP119 (U7) sits at the right-hand tip of the extension.\par}
\end{minipage}

\section*{Firmware: temperature sensing and EEPROM logging}
At each RTC wake, firmware reads the sensors due, saves their data and powers
down. I added TMP119 \textbf{one-shot measurements without averaging} to shorten
active time: a conversion typically takes
\href{https://www.ti.com/lit/ds/symlink/tmp119.pdf\#page=14}{15.5~ms, versus 124~ms for eight averages}.
While TMP119 converts, firmware reads other due sensors, then collects its result
with a timeout. Users can select either temperature sensor or both; the log keeps
their readings separate, records supply voltage and reports missing sensors.

Extra EEPROM page writes cost energy. In R1, I moved the two-byte log pointer
from addresses 7--8 to 8--9 and aligned records to four-byte page boundaries.
This reduces avoidable page crossings at the cost of padding bytes. Firmware
checks that the record fits, waits for its writes to finish, then saves the new
pointer before powering off. If a write cannot be confirmed, it stops.

\section*{Firmware: multirate sampling}
Independent sampling rates allow frequent motion measurements without spending
energy on unnecessary temperature readings. The RTC wakes at the
\textbf{GCD} of the sensor periods; the finite-state machine (FSM) repeats after
their \textbf{LCM}. For temperature/photodiode/acceleration every 120/30/10~s,
the RTC wakes every 10~s: acceleration runs each tick, photodiode every 3 ticks
and temperature every 12 ticks. The cycle repeats after 12 ticks (120~s).
The FSM keeps its step in RTC RAM between MCU power cycles and advances after saving
the data.

\textbf{R2} stores samples together in shared memory; \textbf{R3} gives each
sensor its own region, sized in Android from record size and sampling rate and
fixed during a recording. Suffix \textbf{a} uses the retained FSM; \textbf{b}
calculates the sampling step from RTC time. Keeping the current write positions
in RTC RAM reduces EEPROM updates. Periodic EEPROM checkpoints save these positions
for recovery. Checksums help detect damaged records;
loss of timing stops the recording.

\section*{Android integration and visualization}
One Android app supports \textbf{R1, R2a, R2b, R3a and R3b}, with common-rate or
per-sensor settings. Settings take effect after firmware confirmation; checks
detect changes during NFC reads. Binary/CSV exports and temperature plots use
each sensor's sampling times.

I built \textbf{Sampling lab} to compare selected rates
against synthetic 100~Hz signals and export capacity-checked EEPROM images for
Android debug import. \textbf{EEPROM lab} compares records, padding, page crossings
and allocation across baseline/R1/R2/R3, with adjustable payloads and extra sensors
for packing experiments. These are simulations, not energy measurements.

Recorded checks include all four builds, firmware fault injection, 360 C-generated
images decoded in Java and 14 Android fixture tests on an S21 FE. Energy savings,
unaveraged temperature accuracy and physical power-loss behavior still require
board measurements.

\par\vspace{5pt}
{\color{rulegray}\hrule height 0.5pt}
\vspace{4pt}
{\fontsize{8.5}{10.5}\selectfont\color{muted}\textbf{AI usage.} I used AI for minor KiCad tasks (adding 3D
models and exporting files), literature review, repository documentation,
adapting the Android app to the
firmware using my open-source Android AI development tool,
\href{https://github.com/hashimkarim/android-agent-lab}{Android Agent Lab}, and
creating web apps to visualize EEPROM paging and sampling.\par}
\end{document}

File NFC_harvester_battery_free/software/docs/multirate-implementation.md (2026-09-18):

# R2/R3 implementation and operation

This guide describes the implemented protocol-v5 firmware in this checkout.
See the [software overview](../README.md) for builds, the
[byte protocol](multirate-protocol.md) for serialization, and
[validation record](multirate-validation.md) for evidence and open gates.

## Changes from R1

R1 samples all enabled channels on one common period and writes one padded
record per wake. R2/R3 retain independent LIS2DW12 and TMP119 temperature
selection, photodiode and acceleration, but give each stream its own period.
Both temperature sources can be enabled together, separately, or disabled;
at least one of the four streams must be enabled.

| Behavior | R1, protocol v3 | R2/R3, protocol v5 |
| --- | --- | --- |
| Acquisition | All enabled streams each wake | Only streams due on that base tick |
| Storage | Combined records from byte 128 | Shared pool or partitions from byte 168 |
| Integrity | Metadata CRC; raw pointer and records have no CRC | Record CRC8, paired pointer checkpoints, retained-state CRC16 |
| Scheduling | One period; no missed-wake reconstruction | Retained phase plus RTC checks; timing failures stop the session |
| Configuration | Apply/reset can replace a running session | Stop and acknowledge before Apply/reset |
| Progress | EEPROM pointer every successful wake | RTC RAM each tick; EEPROM checkpoints periodically and on close |

The protocol numbers and revision names are different concepts: R2a, R2b,
R3a and R3b all use version 5. Internal storage ID **1 is partitioned (R3)**
and **2 is shared (R2)**. The `DENSOR2!`/`DNR2` magic is common to both.

## Source organization

All variants share one board entry point and acquisition path in
[`densor_board.c`](../DentalSensor_StorageProject/Core/Src/densor_board.c).
[`densor_multirate.c`](../DentalSensor_StorageProject/Core/Src/densor_multirate.c)
owns metadata, configuration, retained state, checkpoints and recovery.
The Makefile links exactly one `densor_logger_shared.c` or
`densor_logger_partitioned.c`, and one `densor_scheduler_fsm.c` or
`densor_scheduler_rtc.c`. Common byte I/O and CRC16 helpers remain in
`densor_r1.c`; the TMP119 driver is `tmp119.c`.

The Android counterpart is
[`DensorMultirate.java`](../source_ST25NFCApplication_V3_9/app/src/main/java/com/st/st25nfc/densor/DensorMultirate.java).
It validates the same schedule, proposes partition sizes, creates requests,
decodes recordings and labels the detected revision. `DensorNfc.java` provides
verified NFC writes and metadata checks around reads.

## Scheduling and acquisition

The base period is an integer from 1 to 3540 seconds. Each enabled stream has
a positive 16-bit integer multiplier; disabled streams use zero. Its period is
`base × multiplier`, at most 2,592,000 seconds (30 days). The least common
multiple (LCM) of enabled multipliers must fit in 65,535 ticks.

Tick zero samples every enabled stream. Later ticks sample stream `i` when
`tick % multiplier[i] == 0`. With base 10 s and multipliers 12/6/3/1, all
streams sample at 0 s, only acceleration at 10 and 20 s, photodiode plus
acceleration at 30 s, and TMP119 joins them at 60 s. There is a wake on every
base tick, even if no stream is due; empty ticks advance the scheduler without
writing a record. Independent rates reduce acquisitions, but energy savings
must still be measured.

Both schedulers use the RTC calendar and 64 bytes of retained RTC RAM:

- **FSM (a):** selects streams from the retained phase modulo the LCM.
- **RTC time (b):** derives the tick from `(now − session_epoch) / base` and
  checks it against the retained next tick.

Both reject phase loss instead of backfilling missed measurements. Early or
duplicate wakes do not advance the schedule. Lateness tolerance is zero whole
seconds for a 1 s base and one second for a larger base; excessive lateness,
clock rollback or session duration beyond 30 days causes a phase error. These
are software rules, not measured timing guarantees. The RTC-time variant still
requires retained state and does not resume automatically after its loss.

After initializing the EEPROM, firmware rereads the RTC and sets the session
epoch to that reading plus the startup delay (0–59 minutes). Zero delay permits
the first sample on the accepting wake. The epoch is an RTC calendar count
from 2000-01-01, without a UTC synchronization guarantee. Exports use elapsed
seconds, not wall-clock timestamps. Scheduling strategy and crystal/RC oscillator
selection are separate settings; both strategies use the RTC to wake the MCU.

Only due channels are acquired. TMP119 uses bounded, unaveraged one-shots;
its conversion overlaps other sensor work. LIS2DW12 is configured for acquisition
when its temperature or acceleration is due. ADC supply measurement occurs
when a temperature or photodiode channel is due; acceleration-only wakes carry
an unavailable-supply marker. Sensor discovery and TMP119 shutdown still occur
on each boot, even when those channels are not due.

## Storage and full behavior

**R2 shared pool:** each nonempty tick appends a presence mask, supply code,
due payloads and CRC8, then zero-pads to a four-byte boundary. All channels
share the space from byte 168 to the physical capacity. The next complete
record must fit; there is no overwrite or circular buffer.

**R3 partitions:** each enabled stream has a fixed contiguous region. Scalar
records occupy four bytes; acceleration records occupy eight. Android allocates
at least one record to each enabled stream, then distributes remaining pages
in proportion to `record_size × (LCM / multiplier)`, assigning rounding leftovers
in stream order. Firmware validates and commits the supplied boundaries; it
does not calculate a different allocation. Boundaries stay fixed during a session.
The padding rule adds one zero byte only for an unpadded length congruent to
three modulo four; current scalar/acceleration records already need no padding.

Before acquisition, all records due on a tick are checked for available space.
If any would not fit, the whole session becomes FULL without acquiring that
tick. R3 therefore stops at the first limiting partition, even if other
partitions have room. The app previews allocation and expected capacity.

Each committed tick updates alternating retained-state copies. Durable EEPROM
pointer pairs are updated at `min(LCM, 64)`-tick intervals, LCM boundaries, and
Stop/full/error closure. This reduces routine pointer writes relative to R1.
Initialization fills checkpoint/data space with `0xFF`; CRC checks and schedule
validation distinguish records from the unused tail.

## Migration and provisioning

Changing R1 to R2/R3, or changing storage/timing variants, requires exporting
the old data and explicitly initializing the new format. Ordinary boot rejects
legacy, unknown or mismatched metadata without automatically formatting it.

1. Save and check the old full EEPROM binary before migration.
2. Build the intended revision using the [current Makefile commands](../README.md#build-and-check).
3. Use an independently powered bench board and its actual SWD probe. For
   example, this R3a command prepares a **dry run** from the repository root:

   ```sh
   python3 NFC_harvester_battery_free/software/tools/provision_r1.py \
     --protocol multirate \
     --elf NFC_harvester_battery_free/software/DentalSensor_StorageProject/build/partitioned-fsm/densor-r3a-partitioned-fsm.elf \
     --export saved-original.bin --interface interface/stlink.cfg
   ```

4. After verifying the export, ELF and probe selection, adding `--apply` flashes
   the MCU and destructively initializes metadata. The helper uses OpenOCD,
   breaks at `densor_boot_gate` after C initialization, and sets
   `densor_provision_request` to `0x44525035` for multirate firmware.
5. Read the tag with the current Android app and verify the expected R2/R3
   variant, physical capacity and empty STOPPED state before applying settings.

The helper's filename is historical; **`--protocol multirate` is required**.
Its default is R1, and it does not verify that the selected ELF matches that
protocol. The board also needs a valid RTC calendar; this helper does not set
or synchronize it. The physical provisioning sequence remains unvalidated.

## Configure, stop and export

The current app adapts its controls to the detected firmware. R2/R3 settings
show the base period, individual sensor periods, oscillator and startup delay.
The storage and timing strategies require a firmware change to replace.

For a running session, select **Stop and checkpoint recording**. It becomes
a pending request; refresh after the MCU's next wake and wait for STOPPED
with the request acknowledged. Export binary and/or CSV before choosing
**Apply settings and reset log**, which erases the previous recording on
acceptance. An outstanding request must be acknowledged before another is sent.
Stop does not power the board down indefinitely: stopped, full and error states
continue waking at the configured base period, or 120 s before configuration.
There is no extra command-polling loop. During startup delay, a request waits
until the scheduled wake.

Requests are CRC-protected and committed by a separate marker. Android shows
pending values without changing the active session. Firmware rejects Apply
while RUNNING and validates sensor availability and layout before starting the
new session. A valid but rejected request can close the session with an error;
inspect the reported state and acknowledgement rather than assuming success.

R2/R3 binary exports contain the entire physical EEPROM (512/2048/8192 bytes).
The decoder validates records and can scan a valid tail beyond the last EEPROM
checkpoint. Running reads are snapshots; metadata equality before/after a read
does not establish an atomic multi-stream acquisition snapshot. R3 recovery
may preserve different valid tails per stream after an interrupted wake.
Only STOPPED, error-free, acknowledged sessions are labelled complete.
Full/error exports are snapshots or recovered prefixes.

## Recovery and limits

Retained state has paired generations and an in-progress transaction flag.
Missing, ambiguous or interrupted state triggers a CRC-checked record scan
that verifies the durable checkpoint boundaries. A recoverable recording is
closed with a phase/recovery error; it is not silently resumed. A previously stopped recording remains
stopped after retained-state loss. Invalid pointers or corruption before a
checkpoint can prevent recovery entirely.

Configuration is not journaled as a whole. An interrupted CONFIGURING state or
damaged header/status can require saving a raw dump and reprovisioning. CRCs
detect many corruptions but are neither authentication nor proof of atomic
power-loss behavior. If EEPROM completion or a retained-state write is uncertain,
the board halts instead of deliberately cutting power and reacquiring. A bus
failure can also prevent recording the error in EEPROM.

TMP119 startup/shutdown costs, nonvolatile startup provisioning, real NFC
contention, runtime stack use and power-cut recovery still need bench tests.
See the [validation record](multirate-validation.md) before treating a candidate
as a measured hardware result.

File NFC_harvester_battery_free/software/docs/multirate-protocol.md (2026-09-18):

# R2/R3 byte protocol, version 5

This specification follows
[`densor_multirate.c`](../DentalSensor_StorageProject/Core/Src/densor_multirate.c),
the selected logger/scheduler modules and
[`DensorMultirate.java`](../source_ST25NFCApplication_V3_9/app/src/main/java/com/st/st25nfc/densor/DensorMultirate.java).
See the [operation guide](multirate-implementation.md) for lifecycle and recovery.
Integers are unsigned little-endian unless marked signed. Addresses and lengths
are bytes; region ends are exclusive. Structures are serialized explicitly.

## Identity and memory map

All four variants use `DENSOR2!`, header magic `DNR2` and format version 5.
Storage ID 1 means R3 partitions; ID 2 means R2 shared pool. Timing ID 1 means
FSM (suffix a); ID 2 means RTC time (suffix b). Firmware accepts only its
compiled storage/timing pair. Supported physical EEPROM sizes are 512, 2048
and 8192 bytes, checked against the device density at boot and on Android reads.

| Absolute address | Length | Contents / writer |
| --- | --- | --- |
| 0 | 8 | ASCII `DENSOR2!`; firmware format guard |
| 8 | 4 | Reserved zero; not an R1 pointer |
| 12 | 64 | Immutable session header; firmware |
| 76 | 16 | Status and acknowledgement; firmware |
| 92 | 40 | Pending `DCP5` request; Android |
| 132 | 4 | Request commit marker; Android |
| 136 | 32 | Four pairs of durable pointer slots; firmware |
| 168 | capacity − 168 | Record storage; firmware |

Metadata uses CRC-16/CCITT-FALSE (polynomial `0x1021`, initial `0xFFFF`, no
reflection or final XOR; `123456789` → `0x29B1`), stored LE16. Records and
pointer slots use CRC8 (polynomial `0x07`, initial zero, no reflection or final
XOR; `123456789` → `0xF4`). CRCs are integrity checks, not authentication.

## Header at 12

Offsets in this table are relative to the 64-byte header.

| Offset | Bytes | Meaning |
| --- | --- | --- |
| 0 | 4 | ASCII `DNR2` |
| 4 | 1 | Protocol version 5 |
| 5 | 1 | Storage: 1 partitioned, 2 shared |
| 6 | 1 | Header length 64 |
| 7 | 1 | Timing: 1 FSM, 2 RTC time |
| 8 | 2 | Physical EEPROM capacity |
| 10 | 2 | Log start 168 |
| 12 | 1 | Enabled sensor mask |
| 13 | 1 | Reserved zero; no common record stride |
| 14 | 1 | Oscillator: 0 external crystal, 1 internal RC |
| 15 | 1 | Supported sensor mask `0x0F` |
| 16 | 1 | Reserved zero |
| 17 | 1 | Sensors detected when configured |
| 18 | 1 | Startup delay, 0–59 minutes |
| 19 | 1 | Whole-second lateness tolerance: 0 for base 1, otherwise 1 |
| 20 | 4 | Session ID, equal to accepted Apply request ID |
| 24 | 4 | RTC session epoch, seconds from 2000-01-01; not verified UTC |
| 28 | 2 | Base period, 1–3540 seconds |
| 30 | 2 | LCM of enabled multipliers, 1–65535 |
| 32 | 8 | Four LE16 multipliers in sensor order |
| 40 | 8 | Four LE16 region starts |
| 48 | 8 | Four LE16 region ends |
| 56 | 2 | Checkpoint interval in ticks: `min(LCM, 64)` |
| 58 | 4 | Reserved zero |
| 62 | 2 | CRC16 over header bytes 0–61 |

Sensor order and mask bits are: 0 LIS2DW12 temperature (`0x01`), 1 TMP119
temperature (`0x02`), 2 photodiode (`0x04`), 3 acceleration (`0x08`). Unknown
bits are invalid. Enabled multipliers are 1–65535, disabled multipliers zero;
`base × multiplier` must not exceed 2,592,000 s. The epoch must be at most
`3155759999 − 2592000` so the session fits within the supported calendar.

In shared storage only region 0 is populated: start 168, end capacity.
Regions 1–3 are zero regardless of the enabled sensor mask. In partitioned
storage, enabled regions cover `[168, capacity)` contiguously in sensor order;
disabled regions are zero. Boundaries are four-byte aligned, and each enabled
region holds at least one complete record.

A freshly provisioned tag is STOPPED with mask zero. Header bytes 18–57 are
zero, including epoch, session, schedule and boundaries. No pointer slots or
records are interpreted until configuration succeeds.

## Status at 76

| Relative offset | Bytes | Meaning |
| --- | --- | --- |
| 0 | 2 | Status revision, incremented on writes |
| 2 | 1 | 0 STOPPED, 1 CONFIGURING, 2 RUNNING, 3 ERROR, 4 FULL |
| 3 | 1 | Error code |
| 4 | 1 | Last confirmed sensor presence mask |
| 5 | 1 | Reserved zero |
| 6 | 4 | Last acknowledged request ID |
| 10 | 4 | Session ID, matching header |
| 14 | 2 | CRC16 over status bytes 0–13 |

Error codes: 0 none; 1 I/O/write/readiness failure; 2 bad header; 3 bad pointer;
4 invalid configuration; 5 missing/failed selected sensor; 6 no space;
7 invalid state; 8 acquisition timeout; 9 phase/clock/retained-state loss;
10 ambiguous or invalid recovery state. An I/O failure may prevent the error
from being written. Analog photodiode presence is assumed by board design;
there is no identity register to verify its installation.

## Pending request at 92

| Relative offset | Bytes | Meaning |
| --- | --- | --- |
| 0 | 4 | ASCII `DCP5` |
| 4 | 4 | Request ID, greater than acknowledged ID; no wrap |
| 8 | 1 | Command: 1 Stop/checkpoint, 2 Apply settings/reset |
| 9 | 1 | Requested sensor mask |
| 10 | 1 | Oscillator |
| 11 | 1 | Protocol version 5 |
| 12 | 2 | Base period in seconds |
| 14 | 8 | Four LE16 multipliers |
| 22 | 4 | Expected current session ID |
| 26 | 1 | Startup delay in minutes |
| 27 | 1 | Installed storage ID |
| 28 | 1 | Installed timing ID |
| 29 | 1 | Reserved zero |
| 30 | 8 | Four LE16 allocation counts in four-byte pages |
| 38 | 2 | CRC16 over request bytes 0–37 |

Android clears and verifies the marker at 132, writes/verifies the body in
four-byte chunks, then writes/verifies the request ID as the marker. Firmware
reads marker/body/marker; mismatched IDs, changed markers or a bad CRC leave
the request inactive. IDs at or below the acknowledged ID are ignored.
Only one request may be outstanding.

For Apply, page counts describe the new immutable allocation. R2 uses
`[(capacity − 168) / 4, 0, 0, 0]`; R3 uses the Android allocation described in
the [implementation guide](multirate-implementation.md#storage-and-full-behavior).
The counts must cover the data region exactly and satisfy enabled-stream bounds.
Stop does not apply the proposed schedule or allocation, but still validates
request identity, version, strategies and expected session.

Apply is rejected while RUNNING. After validation, firmware writes CONFIGURING,
fills bytes 136 through the end with `0xFF`, initializes pointer pairs, rereads
the RTC, writes the new header and retained state, then acknowledges RUNNING.
The first-sample epoch includes startup delay. Stop checkpoints the pointers
and acknowledges STOPPED. Incomplete initialization is not automatically retried;
CONFIGURING or inconsistent metadata requires recovery/provisioning attention.

## Durable pointers at 136

Region `i` has two four-byte slots at `136 + 8i` and `140 + 8i`:

| Slot offset | Bytes | Meaning |
| --- | --- | --- |
| 0 | 2 | Absolute next-write address |
| 2 | 1 | Generation, modulo 256 |
| 3 | 1 | CRC8 over bytes 0–2 |

Initialization writes two identical generation-zero pointers to the region
start. Later checkpoints increment the generation and alternate by its low
bit. A CRC-valid pointer must lie within its region and match the record stride
(four-byte alignment for shared storage). Among two valid slots, modular
generation difference 1–127 selects the newer; 128 is ambiguous. Equal
generations must have identical content. Invalid or ambiguous pairs fail closed.
Unused regions have no interpreted checkpoint.

## Records

| Sensor | Payload bytes | Decoding |
| --- | --- | --- |
| LIS2DW12 temperature | 2 signed LE16 | `raw / 256 + 25` °C |
| TMP119 temperature | 2 signed LE16 | `raw / 128` °C |
| Photodiode | 2 LE16 | ADC code 0–4095 |
| Acceleration | 6, three signed LE16 | X/Y/Z, each `raw / 16384` g |

These conversions describe the implemented decoder, not new accuracy claims.
Supply codes 0–15 represent `(18 + code) / 10` volts. Code `0xFF` means absent.
A wake with any temperature or photodiode due requires code 0–15; an
acceleration-only wake requires `0xFF`. On a mixed wake, the same measured supply
code is copied into every partitioned record, including acceleration.

**R2 shared:** `mask:u8 | supply:u8 | payloads in sensor order | crc8 | zero pad`.
CRC covers mask, supply and payloads, excluding padding. Stored length is
`round_up_to_4(3 + sum(payload_lengths))`. A single scalar uses 8 bytes;
acceleration alone uses 12; all channels use 16. Empty ticks write no record.
The mask must match the next nonempty tick implied by the schedule.

**R3 partitioned:** `payload | supply:u8 | crc8`. Temperature/photodiode records
use 4 bytes and acceleration uses 8. CRC covers payload and supply. The general
padding rule adds a zero only when the unpadded length has remainder 3 modulo
4; current record lengths already have remainder zero. Partition identity
supplies the channel; there is no per-record presence mask.

Records contain no timestamp. The `n`th partitioned record belongs to tick
`n × multiplier`; shared records follow successive nonempty scheduled ticks.
Elapsed time is `tick × base`. Independent fixed byte vectors are in
[`multirate-record-fixtures.json`](../tests/multirate-record-fixtures.json).

## Retained RTC state

The first 64 RTC RAM bytes hold two 32-byte copies, separate from EEPROM and
absent from NFC dumps. Board access uses RTC RAM bank zero.

| Copy-relative offset | Bytes | Meaning |
| --- | --- | --- |
| 0 | 2 | ASCII `R5` |
| 2 | 1 | Generation, modulo 256 |
| 3 | 1 | 0 clean, 1 transaction in progress |
| 4 | 4 | Session ID |
| 8 | 4 | Session epoch |
| 12 | 4 | Next base tick |
| 16 | 2 | Phase, `next_tick % LCM` |
| 18 | 8 | Four LE16 working pointers |
| 26 | 4 | Four durable-pointer generation bytes |
| 30 | 2 | CRC16 over bytes 0–29 |

Copies alternate and are read back after writing. Before appending, firmware
persists an in-progress copy; after record writes and any due checkpoint it
advances the schedule and writes a clean copy. Checkpointing occurs when the
next tick is divisible by `min(LCM, 64)` or the LCM, and on closure.

After retained-state loss or an interrupted transaction, recovery scans records
from region starts, validates the durable checkpoint boundary and advances to
the valid tail. It then checkpoints and closes a non-stopped session with an
error. It cannot reconstruct missing measurements or guarantee an all-channel
atomic wake. A stopped session remains stopped; corrupt data before a durable
checkpoint or ambiguous generations can prevent recovery.

## Reading and compatibility

R2/R3 decoding requires a full physical EEPROM dump. The reader validates
header/status, allocations, pointer slots, CRCs, masks, supply and padding,
and scans to the first invalid tail. Corruption before a checkpoint is rejected;
a STOPPED image with a valid uncheckpointed tail is also rejected. Running/full/
error images are labelled snapshots or recovered prefixes. A complete recording
requires STOPPED, error zero and no outstanding request.

R1 v3 uses a different guard, 128-byte metadata and request format; original
legacy and R1 v2 recordings are read-only in the current app. Unsupported
multirate versions are rejected. Export before switching variants and explicitly
reprovision; changing the header's strategy bytes is not a format conversion.

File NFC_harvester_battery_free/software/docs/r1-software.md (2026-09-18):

# Densor R1 software candidate (historical reference)

For current R2/R3 firmware, start with the [software overview](../README.md)
and [multirate implementation guide](multirate-implementation.md). The operation,
APK version and test evidence below describe R1; R2/R3 use a different protocol
and require Stop before applying settings.

For synthetic multirate sampling experiments, use the local
[Sampling lab webapp](../../visualization/sampling_lab/README.md). It previews independent sensor
rates and exports lab binaries or full R1/R2a/R2b/R3a/R3b EEPROM images for
Android debug import, with synthetic provenance and capacity checks.

The [visualization folder](../../visualization/README.md) also contains the
[EEPROM lab](../../visualization/eeprom_lab/README.md) for comparing memory layouts
and page crossings.

R1 implements aligned combined logging, independent LIS2DW12/TMP119 temperature
selection and a matching Android reader/configurator. It is a **software-tested
candidate**, with hardware validation still pending.

The [byte protocol](r1-protocol.md) defines the 128-byte metadata map,
settings/reset transaction, legacy detection and record encoding. Source lives in
[`DentalSensor_StorageProject`](../DentalSensor_StorageProject) and
[`source_ST25NFCApplication_V3_9`](../source_ST25NFCApplication_V3_9).

## Historical build and check

The commands and artifact names below describe the R1 candidate checkout.
They are not an R1 build recipe for the current tree: plain `make` now selects
R3a, and `build_r1.py` still expects the older R1 output paths and APK version.
Use the [current build instructions](../README.md#build-and-check) for R2/R3.
`test_r1.py` remains valid for compatibility testing.

Historical commands, from the repository root:

```sh
python3 NFC_harvester_battery_free/software/tools/test_r1.py
make -C NFC_harvester_battery_free/software/DentalSensor_StorageProject -j4
python3 NFC_harvester_battery_free/software/tools/build_r1.py
```

Set `JAVA_HOME` to your JDK 17 installation and `ANDROID_HOME` (or
`ANDROID_SDK_ROOT`) to your Android SDK. The helper also accepts `--java-home`
and `--sdk` paths relative to the directory where you invoke it.
Required SDK components are Android
33 and build-tools 35.0.0. The wrapper pins Gradle 8.9; the app uses AGP 8.7.1.
The build helper creates a local SDK view so the old lint parser does not scan
unrelated preview SDK names. It does not change the installed SDK. The ARM
compiler is `arm-none-eabi-gcc`; the host fault tests use Clang and address/
undefined-behavior sanitizers by default. `DENSOR_SANITIZE=0` is an explicit
fallback on hosts without sanitizer runtimes and is reported as such.

Firmware is optimized with `-Os` and includes debug symbols, `.su` compiler stack
reports and the linker map. Physical linker limits remain 16,384 bytes Flash and
2,048 bytes SRAM; the 512-byte heap and 1,024-byte stack reservations are retained.
Inspect the map, `.su` reports and [stack review](r1-stack-review.md)
together; those reservations are not a measured runtime stack margin.

Historical candidate artifacts were generated in `software/build/r1-candidate/`:

- `densor-r1.bin`, `.hex`, `.elf` and `.map`.
- `ST25NFCTap-signed-V3.10.2-r1.apk` and AGP output metadata.
- Protocol, build/test logs, APK manifest/signature checks, ELF measurements,
  source hashes/build manifest and `SHA256SUMS`.

The APK is the non-debuggable **release variant** of `com.st.st25nfc`, version
`3.10.2-r1`, version code 28, minimum Android 6/API 23, target API 33. It retains
the project's existing local debug signing configuration. Its certificate is
recorded in the manifest, but compatibility with an installed older APK has not
been verified. No app-specific production signing profile is configured, so the
Android deployment doctor's profile-based release check is pending. Do not
publish this candidate as a signed-off upgrade or rotate an existing deployed
key to work around an installation failure.

## Migration and operation

1. Save the old binary log before flashing. The new app reads validated legacy
   recordings and labels them as snapshots; it does not configure legacy tags.
2. On a powered bench board, explicitly initialize R1 through SWD after checking
   that export. The helper defaults to a dry run:

   ```sh
   python3 NFC_harvester_battery_free/software/tools/provision_r1.py \
     --elf NFC_harvester_battery_free/software/build/r1-candidate/densor-r1.elf \
     --export saved-original.bin --interface interface/stlink.cfg
   ```

   Choose the actual probe configuration. Adding `--apply` flashes the ELF and
   requests destructive initialization through a firmware breakpoint. Confirm
   the stopped R1 header in Android afterwards. This sequence has not been
   exercised on a physical board. Normal firmware boot leaves legacy/unknown
   layouts alone; Android cannot initiate new-format writes to a legacy tag.
3. In Settings, choose old-only, TMP119-only, both, or no temperature, and enable
   photodiode/acceleration independently. Use one common period: 1–59 seconds or
   whole minutes up to 3,540 seconds. The optional **startup delay** is 0–59
   minutes; zero starts immediately. **Apply settings and reset log** is accepted
   on the next regular wake, then the first measurement follows that one-time delay. Active and pending settings remain
   distinct until the MCU accepts the request. No separate Start/Stop sequence.
4. **Reset log using current settings** restarts at the beginning with the same
   sensors, period and startup delay. Save existing data first. Applying/resetting settings
   replaces the previous recording; firmware validates the complete request and
   selected sensors before accepting it.
5. Read/save binary or CSV in Data at any time. Reads check that metadata and
   pointer stay unchanged; retry if the board wakes during the read. Running
   recordings are labelled **live snapshots**, which exclude later samples.
   Full/error exports contain the stable committed prefix. CSV and plots keep
   separate old/TMP119 values and leave unavailable supply readings blank.

Except for the one-time startup delay, all ordinary wakes use the configured sampling interval, including full/error
states. There is no separate five-second command-polling loop. Before valid
settings exist, the default is 120 seconds. Full/error states skip acquisition
until a valid settings/reset request is accepted. Actual idle/sampling power
remains unmeasured. Missing selected sensors cause explicit errors; TMP119-only
does not initialize LIS2DW12 unless acceleration is enabled.

Protocol version 3 supports the startup delay within the settings/reset contract.
Original legacy and version-2 recordings remain readable;
version-2 firmware is read-only in this app. Export before updating firmware and
explicitly reprovisioning. The delay is consumed before sleeping, so an unexpected
power loss before RTC power-off can shorten or skip it, as in the original firmware.

R1 does not establish UTC from a delayed phone command. Its header explicitly
marks UTC unavailable; graphs/exports use sample indices and nominal elapsed
seconds. R1 cannot reconstruct missed wakes. Existing charge-mode timestamp
bytes are never displayed as a voltage in an R1 header. Older Android versions
must not configure new-format firmware.

TMP119 uses unaveraged one-shots with finite bus/readiness deadlines, overlapping
LIS2DW12/ADC work. Firmware shuts a fitted sensor down on every wake before use,
including when temperature is disabled. It does not program TMP119 nonvolatile
settings automatically. A verified once-only shutdown-startup provisioning
procedure and its power-cycle check remain a bench task; otherwise startup and
shutdown energy must be counted. Individual samples do not inherit the accuracy
specification for averaged conversions.

## Evidence and remaining gates

Host checks exercise all 15 nonempty sensor masks, 512/2,048/8,192-byte memory
bounds, exact-full memory, page boundaries, signed temperatures, supply fields,
padding, incomplete/duplicate requests, sensor availability, failed transmission
and readiness, interrupted configuration commits, and bounded TMP119 polling
including tick wrap. Another 110 scenarios run the real board entry point with a
fake HAL and check RTC alarm writes, settings/reset transitions, full/error
intervals, startup delay followed by normal sampling, and fault halts. These do not measure physical power. Java decodes 45 C-produced EEPROM images plus fixed binary
vectors and legacy records, and rejects damaged/unknown metadata and padding.
The [historical-data fixtures](../tests/HISTORICAL_DATA.md) also compare all 210
reconstructed samples from an existing CSV between legacy and R1 decoding.
They are explicitly labelled reconstructions; the old raw NFC dumps are absent.
Release vital lint is enabled. The pre-Android-12 NFC PendingIntent branches have
narrow false-positive lint suppressions; their Android-12 guards remain intact.
The [Android NFC documentation](https://developer.android.com/develop/connectivity/nfc/advanced-nfc)
requires mutability for foreground dispatch to populate tag information.

[Phone checks](android-phone-tests.md) cover APK installation/launch and
six fixture-based Android tests on the USB-connected S21 FE (Android 16). The
fixture host is included only in a test build. The release APK is restored after
testing. Physical NFC communication remains unmeasured.

The [build table](../measurements/build-results.csv) and
[run template](../measurements/run-results.csv) distinguish measured software
allocation from unmeasured physical results. Empty cells are unmeasured.

| Gate | Status |
| --- | --- |
| Firmware build and physical linker limits | Checked by candidate build |
| Portable storage/driver fault tests and golden decoding | Checked by host tests |
| Android release build, vital lint, manifest and signature | Checked by candidate build |
| Actual ST25DV density and sensor identity/wiring | Unmeasured; firmware reads density at runtime |
| Physical power-loss, NFC contention and actual device logs | Unmeasured |
| Stack high-water, interrupt margin, heap peak | Unmeasured; `.su` and map available |
| Energy, wake duration, bus/page-program counts at 2.6/2.2/1.8 V | Unmeasured |
| TMP119 startup provisioning and power-cycle readback | Unmeasured |
| APK installation/launch and same-signer reinstall on S21 FE | Checked; see phone evidence |
| Android fixture decoding, settings/reset and plots | Six instrumented tests; see phone evidence |
| Real NFC exchange and compatibility with the original deployed signer | Unmeasured / unverified |

R1 keeps one raw two-byte pointer write per successful wake. Padding reduces
avoidable page programming but does not eliminate pointer wear, add record CRCs
or provide torn-write recovery. An aligned corrupt pointer may be undetectable;
power loss can leave an orphan record or incomplete metadata. If EEPROM
programming completion cannot be confirmed, firmware halts instead of
deliberately cutting power or resetting into a duplicate acquisition. A failed
bus may prevent saving the error status. See the protocol before recovery.

Before release, run the voltage/sensor matrix in `measurements/run-results.csv`, measure
runtime stack and energy, establish Android signing/upgrade compatibility,
confirm migration on hardware and bind the exact source revision to the release.

## Debug mode without a board

Build `:app:assembleDebug`, open **ST25 dbg**, and select **Debug mode** to use a
virtual EEPROM with the R1 protocol.
The debug package `com.st.st25nfc.dbg` can coexist with the release app. Its virtual
tag and activity are excluded from release builds.

Use **Samples** for a synthetic both-temperature recording or the 210-sample
historical CSV reconstructed as legacy/R1. Those are test fixtures, not original
raw NFC captures; the historical data has no TMP119 samples. **Settings**, **Data**
and **Reset** run the same fragments and protocol code as the real app. Applying
settings (including startup delay) writes a checked pending request. There is no
firmware simulator: no acknowledgement, new samples or timing/power measurement.

**Open .bin** imports a raw image starting at EEPROM address zero. It must contain
all bytes through the committed pointer. R1 uses its header's declared capacity;
legacy full 512/2048-byte images retain that size, while a legacy prefix is modelled
with 8192 virtual bytes because it has no density field. Only the unused tail is
zero-filled. Bad headers, truncated records and invalid padding are rejected
without replacing the current image. Legacy/version-2 settings remain read-only.
**Export .bin** saves the full virtual memory, including a pending request. Import
leaves the source file untouched. Export before leaving or replacing the image;
virtual memory survives activity recreation but is not saved as an app document.

Run `:app:testDebugUnitTest` for the debug UI/import/export/validation tests.

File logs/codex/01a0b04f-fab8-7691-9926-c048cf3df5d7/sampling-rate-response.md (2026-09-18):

For **different fixed rates per sensor, I would prioritize acceleration**, followed by light, with temperature sampled more slowly. That ranking concerns **useful changes over time**; raw variances in acceleration, light intensity, and temperature have different units and cannot be compared directly.

The strongest evidence is:

- **Acceleration:** Martinot et al. report rhythmic jaw movements during sleep bruxism at **0.5–1.5 Hz**—one cycle every **0.7–2 seconds**. Chun et al.’s intraoral system sampled acceleration at **54 Hz** and used **4-second windows** for chewing detection. A sample every 120 seconds loses these movement patterns almost entirely, although it can still capture head orientation. Martinot used a chin-mounted accelerometer and gyroscope, so its results establish relevant timescales rather than Densor’s detection accuracy. [Martinot, 2021](https://pmc.ncbi.nlm.nih.gov/articles/PMC8397703/), [Chun, 2020](https://users.ece.utexas.edu/~ethomaz/papers/c13.pdf)
- **Light:** Densor itself detects speaking through **light-intensity variance during 30-second recordings**, collected at **1 Hz**. Sampling every 120 seconds can miss the entire recording interval. This is the most direct example already demonstrated on Densor, but it depends on sufficient ambient illumination. [Densor, §7.2](https://research.tudelft.nl/files/231268124/3699746.pdf)
- **Temperature:** Faster sampling helps capture drinking-related temperature dips and their slopes. For slower temperature trends, the benefit is smaller; sensor placement and encapsulation also affect the response. [Densor, §7.2](https://research.tudelft.nl/files/231268124/3699746.pdf)

For your mock comparison, these would be reasonable **starting settings to test**, not established optimal rates:

| Signal | Synthetic curve | Fixed sampling rate |
|---|---|---:|
| Acceleration | Gravity/posture baseline plus short bursts of 0.5–1.5 Hz jaw movement | **25 Hz** |
| Light | Open/closed levels plus irregular fluctuations during speaking | **1 Hz** |
| Temperature | Slow drift plus a cool-water dip and gradual recovery | **0.1 Hz — every 10 s** |

Use the **same underlying curves** for every sampling strategy. Randomize event onset relative to the sampling clock and repeat across different event durations, amplitudes, and noise levels. Label those choices as simulation assumptions.

I’d compare three conditions:

1. **Original:** all three signals every 120 seconds.
2. **Multirate:** the rates above.
3. **Uniform fast:** all three at 25 Hz, to measure how many readings multirate avoids while preserving detection performance.

Report **event recall, false positives, timing error, and sample/storage counts**. For acceleration, also measure how accurately the movement frequency is recovered. Avoid relying only on curve reconstruction error: long quiet periods can hide poor detection of short events.

One firmware constraint matters: the [current sampling loop](/mnt/shared/Git/densor/NFC_harvester_battery_free/software/DentalSensor_StorageProject/Core/Src/main.c:511) reads all enabled sensors, stores a record, and powers down until a shared RTC alarm. Supporting 25 Hz needs a different acquisition schedule. Track energy separately—fewer sensor readings do not translate directly into proportional energy savings.

Your simulation can quantify **detection improvements under the modeled conditions**. Validating the improvement on real Densor signals would then require labeled recordings at a sufficiently high rate.

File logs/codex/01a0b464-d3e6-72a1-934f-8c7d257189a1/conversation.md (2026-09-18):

# LLM Interaction Log

- Agent: `codex`
- Thread ID: `01a0b464-d3e6-72a1-934f-8c7d257189a1`
- Log created: `2026-09-18T16:30:28+02:00`

## Interaction 1

### Input

> Write documentation for R1, the corrected baseline of the battery-free Densor
> project. R1 adds TMP119 temperature
> sensing, selection of the existing LIS2DW12 temperature sensor, TMP119 or both,
> and page-aligned and padded EEPROM storage. All enabled channels are sampled
> at each wake using one shared sampling interval.
>
> First review the diffs. Check the hardware and firmware
> changes. Base the documentation on the implemented behavior and current agreed
> scope. Flag discrepancies between the code and existing documentation.
>
> Explain what changed and why, including TMP119 integration, temperature modes,
> EEPROM alignment and padding, and the memory layout and record format.
> Include firmware build and usage instructions,
> migration from the original version, compatibility limits and how to run the
> tests. Summarize the available test evidence and known limitations, making clear
> which hardware checks remain pending. Keep it focused on R1 and update the
> existing documentation where appropriate.

### Output

> Documented R1 firmware changes, the data format, build instructions
> and testing.

## Interaction 2

### Input

> ok now make the android app compatible with the new firmware, use my android agent lab for repeated real tests using both the simulator and my S21 FE connected in USB debugging mode

### Output

> Updated the Android app for R1 with compatible record decoding, temperature
> selection, configure/reset controls, separate temperature plots and CSV/binary
> exports. Added a simulated EEPROM debug mode and registered the project in
> Android Agent Lab. Simulation tests and six UI tests on the USB-connected
> S21 FE passed.

## Interaction 3

### Input

> Iterate on the Android app to support the updated R1 firmware and R2/R3.
> One app should support all three revisions simultaneously, detecting the
> firmware or dump format and adapting its settings and data decoding.
> For R2/R3, support both timing variants: a = FSM and b = RTC timer, covering
> R2a, R2b, R3a and R3b. Use the finalized naming: R2 = shared pool and
> R3 = partitions.
>
> Allow the app's debug mode to import firmware-compatible EEPROM `.bin` dumps
> generated by the synthetic sampling webapp, so sampling settings and decoded
> data can be tested without a Densor board.
>
> Use Android Agent Lab and the USB-connected Samsung S21 FE for repeated app
> testing, including dump import, settings changes, read-back, plots and export.

### Output

> Updated the Android app to support R1, R2 and R3 in one app, with automatic
> format detection and revision-specific settings and decoding. Both multirate
> timing modes are supported: a = FSM and b = RTC timer, covering R2a/R2b
> (shared pool) and R3a/R3b (partitions).
>
> Debug mode accepts firmware-compatible EEPROM `.bin` dumps from the synthetic
> sampling webapp for viewing data and testing sampling settings. Validated the
> debug workflow using Android Agent Lab and the USB-connected S21 FE, including
> import, settings changes, read-back, export and reopening saved dumps. Physical
> Densor sampling timing and NFC hardware behavior still require board testing.

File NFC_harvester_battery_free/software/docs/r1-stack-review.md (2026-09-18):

# R1 stack review (software evidence only)

Toolchain: ARM GNU GCC 15.2.0, Cortex-M0+, `-Os -g3 -fstack-usage`, no LTO.
The candidate includes the ELF, linker map and concatenated compiler `.su`
reports in `compiler-stack-usage.tsv`. Recompute this review if code or flags
change. Compiler frames are estimates for individual functions, not observed
runtime high-water marks.

The startup-delay restoration adds 72 Flash bytes (13,504 total) and leaves the
reviewed frames below unchanged. The linked R1 image has 312 bytes of static SRAM, a 512-byte heap reservation,
a 1,024-byte stack reservation and 200 bytes outside those linked allocations.
Those 200 bytes are **not** a measured remaining stack margin. The application
uses fixed-size buffers. No `malloc`, `calloc`, `realloc`, `free` or printf
implementation is linked in this image; the heap reservation is unchanged.

The source and `.su` review identifies these important paths:

| Path | Sum of listed compiler frames |
| --- | ---: |
| `main` → `SystemClock_Config` → `HAL_RCC_OscConfig` | 56 + 104 + 40 = 200 B, before deeper HAL calls |
| `main` → `densor_board_run` → `densor_request` → `status_write` → `densor_write` → `write_memory` → `write_reg` → `HAL_I2C_Mem_Write` → `I2C_WaitOnTXISFlagUntilTimeout` → `I2C_IsErrorOccurred` | 56 + 80 + 96 + 24 + 32 + 16 + 32 + 48 + 24 + 32 = 440 B |
| `main` → `densor_board_run` → `tmp119_result` → `tmp_read` → `read_reg` → `HAL_I2C_Mem_Read` | 56 + 80 + 40 + 32 + 32 + 48 = 288 B, before deeper HAL calls |

The memory and TMP119 callbacks are indirect calls; they are included explicitly
in the paths above. Several acquisition helpers are inlined into
`densor_board_run`, whose frame already includes their local storage. Tail calls
may make a summed path conservative. These selected paths are not a proof of
the global worst case: compiler runtime routines and assembly also need review.

Normal acquisition uses polling rather than DMA or peripheral interrupts. The
enabled SysTick handler has an 8-byte compiler frame and calls `HAL_IncTick`
(0-byte reported frame). Cortex-M exception entry additionally stacks eight
registers (32 bytes), with possible alignment padding. Fault/NMI handlers loop;
they do not perform logging or formatted output. The startup vector table and
HAL clock setup must be revisited if interrupt use changes.

Before publication, fill SRAM with a known pattern without overwriting live
state, exercise the full sensor/configuration/error matrix on the board, inspect
the lowest untouched stack address, and account for interrupt nesting. Record
peak stack, peak heap and remaining margin separately. **All physical stack,
heap and interrupt-margin measurements remain unmeasured.** No linker limit or
reservation was changed to make the build fit.

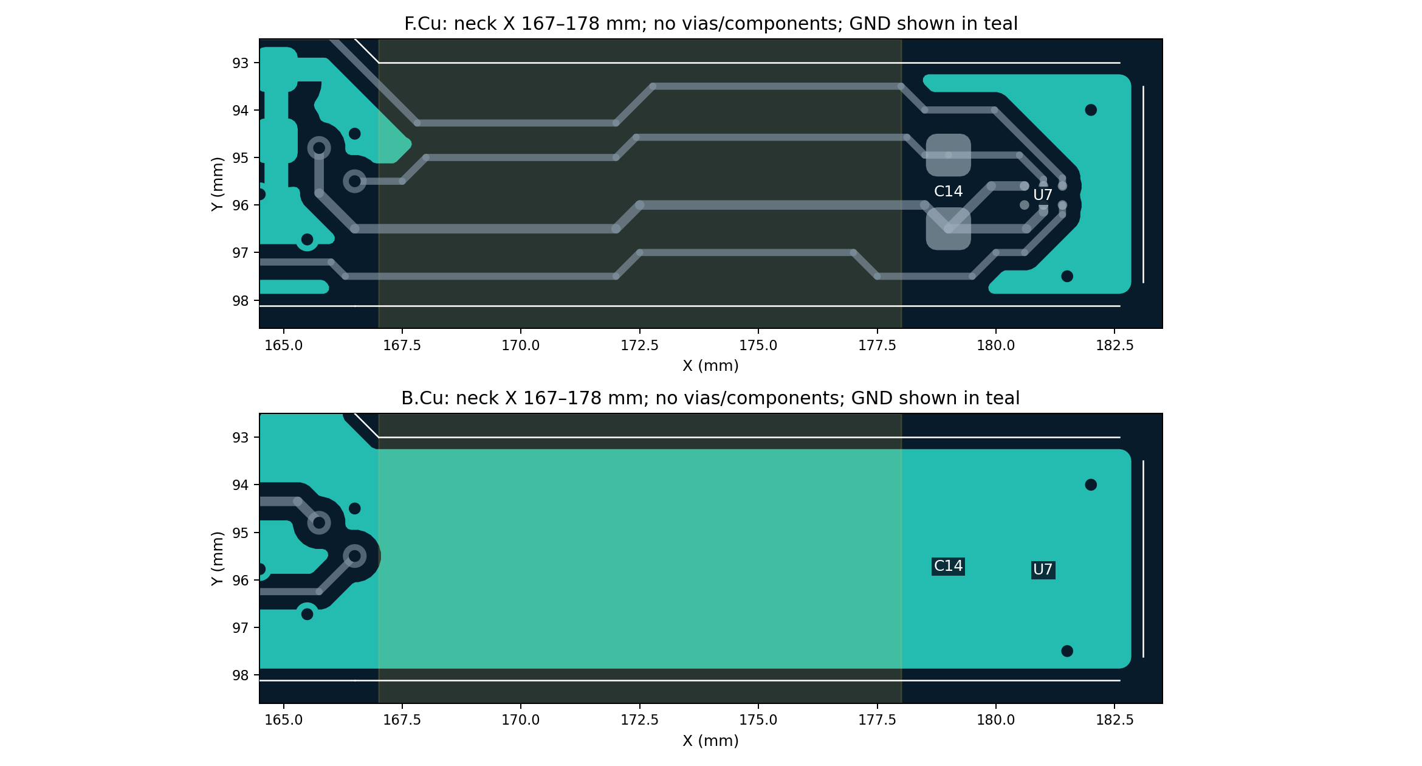
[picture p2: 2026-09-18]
NFC_harvester_battery_free/hardware/exports/extension-copper.png

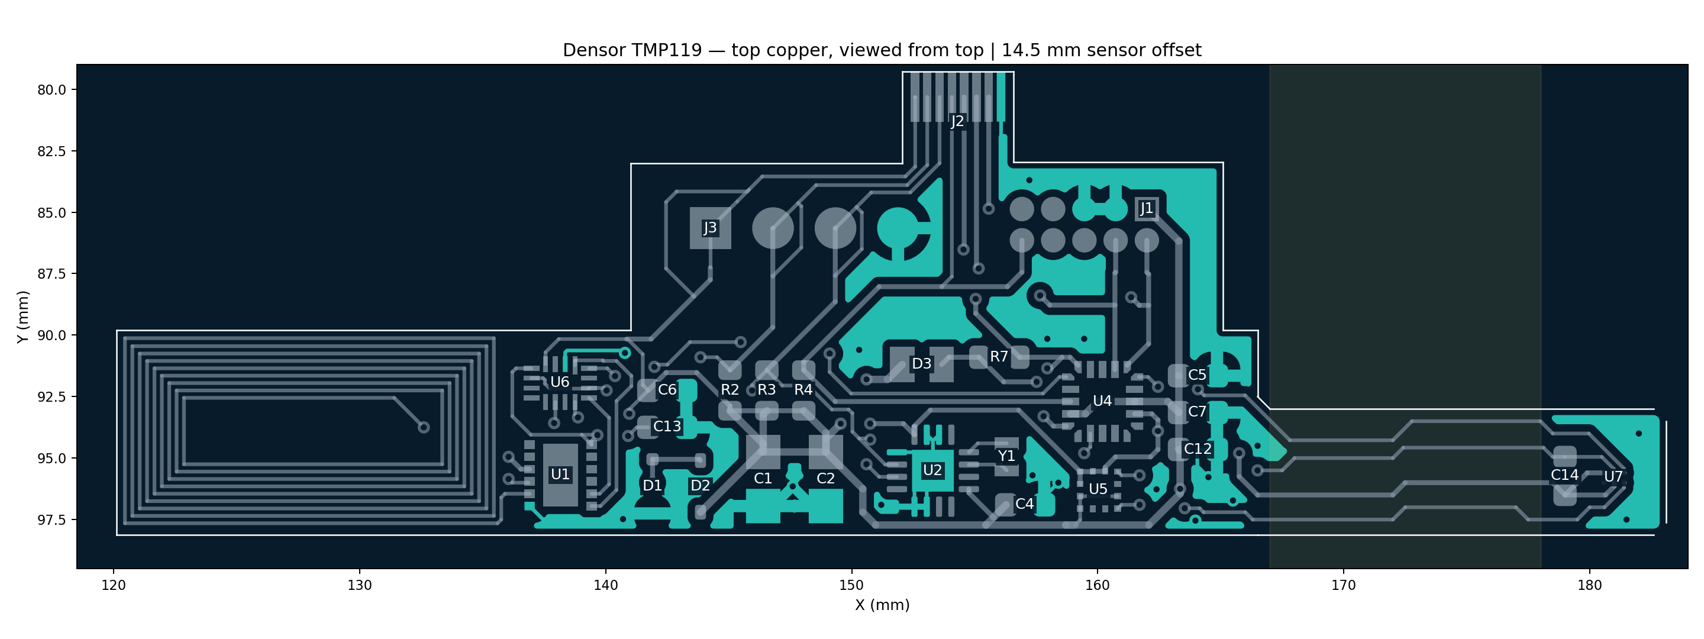
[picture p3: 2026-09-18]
NFC_harvester_battery_free/hardware/exports/top-copper.png

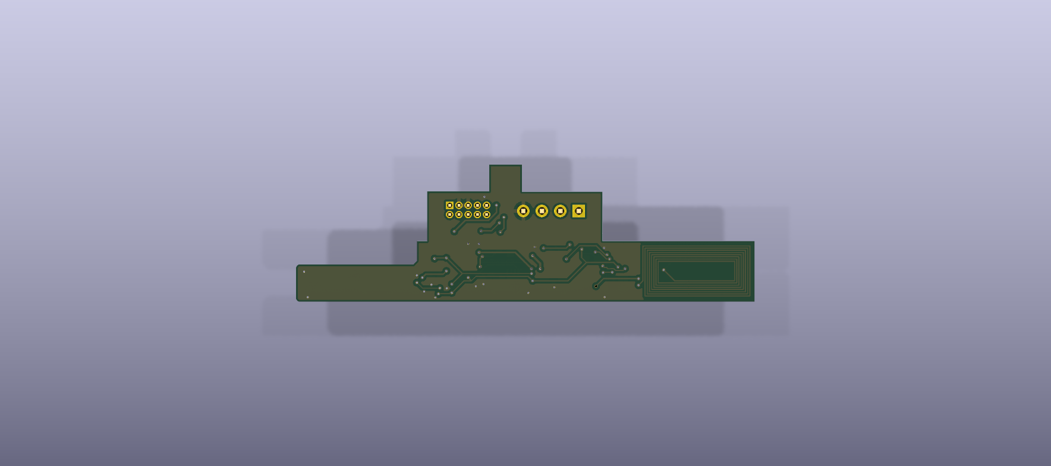
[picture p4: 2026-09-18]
NFC_harvester_battery_free/hardware/exports/3d-bottom.png

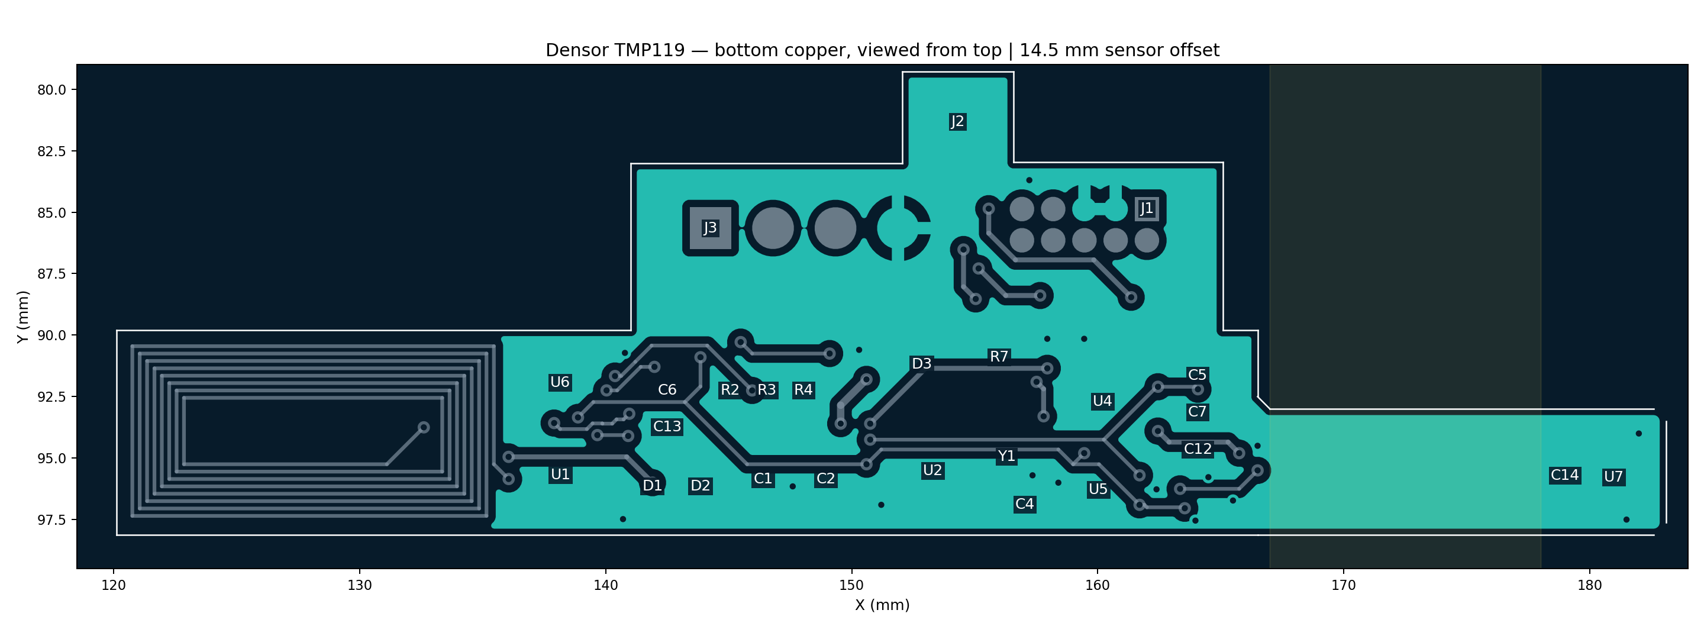
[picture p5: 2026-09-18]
NFC_harvester_battery_free/hardware/exports/bottom-copper.png

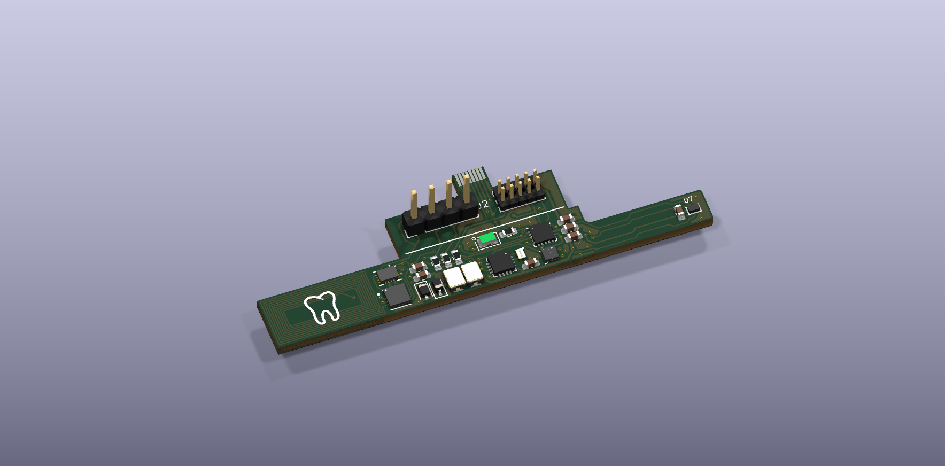
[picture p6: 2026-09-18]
NFC_harvester_battery_free/hardware/exports/3d-oblique.png

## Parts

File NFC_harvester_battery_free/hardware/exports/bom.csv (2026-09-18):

References | Value | Footprint | Quantity | MPN | Manufacturer | DNP
C1,C2 | C_Polarized | antennas:CPX3225A | 2
C4-C7,C12,C13 | 100n | Capacitor_SMD:C_0603_1608Metric | 6
C14 | 100n | Densor:C_0603_1608Metric | 1
D1 | D_Zener_3v3 | Diode_SMD:D_SOD-323F | 1
D2 | BAS316 | Diode_SMD:D_SOD-323 | 1
D3 | D_Photo | antennas:pd_vemd1060x01 | 1
J1 | Conn_ARM_JTAG_SWD_10 | Connector_PinHeader_1.27mm:PinHeader_2x05_P1.27mm_Vertical | 1
J2 | Conn_01x08_Pin | antennas:fpc_503480-0800 | 1
J3 | Conn_01x04_Pin | Connector_PinHeader_2.54mm:PinHeader_1x04_P2.54mm_Vertical | 1
R2-R4 | 100k | Resistor_SMD:R_0603_1608Metric | 3
R7 | R | Resistor_SMD:R_0603_1608Metric | 1
U1 | ST25DV04K-JFR6D3 | ST25DV04K-JFR6D3:PSON50P300X300X60-13N | 1
U2 | AM1805 | Package_DFN_QFN:QFN-16-1EP_3x3mm_P0.5mm_EP1.7x1.7mm | 1
U4 | STM32L011F3Ux | Package_DFN_QFN:ST_UFQFPN-20_3x3mm_P0.5mm | 1
U5 | LIS2DW12 | Package_LGA:Kionix_LGA-12_2x2mm_P0.5mm_LayoutBorder2x4y | 1
U6 | TS3A44159 | antennas:RSV16 | 1
U7 | TMP119 | Densor:DSBGA6_YBG_TEX | 1 | TMP119AIYBGR | Texas Instruments
Y1 | Crystal | antennas:ABS05W_Crystal | 1

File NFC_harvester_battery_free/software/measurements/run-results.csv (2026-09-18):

release | source_revision | temperature_mode | photodiode_enabled | acceleration_enabled | common_interval_s | supply_voltage_v | status | old_temperature_valid_samples | tmp119_valid_samples | photodiode_valid_samples | acceleration_valid_samples | old_temperature_conversions | tmp119_conversions | due_masks | i2c_bytes | rtc_reads | rtc_writes | eeprom_data_page_programs | eeprom_metadata_page_programs | wake_duration_ms | supply_current_ua | integrated_energy_uj | off_state_leakage_ua | initialization_energy_uj | recovery_energy_uj | notes
R1 |  | old-only | false | false | 120 | 2.6 | unmeasured |  |  |  |  |  |  |  |  |  |  |  |  |  |  |  |  |  |  | No hardware available.
R1 |  | old-only | false | false | 10 | 2.6 | unmeasured |  |  |  |  |  |  |  |  |  |  |  |  |  |  |  |  |  |  | No hardware available.
R1 |  | old-only | false | false | 120 | 2.2 | unmeasured |  |  |  |  |  |  |  |  |  |  |  |  |  |  |  |  |  |  | No hardware available.
R1 |  | old-only | false | false | 10 | 2.2 | unmeasured |  |  |  |  |  |  |  |  |  |  |  |  |  |  |  |  |  |  | No hardware available.
R1 |  | old-only | false | false | 120 | 1.8 | unmeasured |  |  |  |  |  |  |  |  |  |  |  |  |  |  |  |  |  |  | No hardware available.
R1 |  | old-only | false | false | 10 | 1.8 | unmeasured |  |  |  |  |  |  |  |  |  |  |  |  |  |  |  |  |  |  | No hardware available.
R1 |  | old-only | false | true | 120 | 2.6 | unmeasured |  |  |  |  |  |  |  |  |  |  |  |  |  |  |  |  |  |  | No hardware available.
R1 |  | old-only | false | true | 10 | 2.6 | unmeasured |  |  |  |  |  |  |  |  |  |  |  |  |  |  |  |  |  |  | No hardware available.
R1 |  | old-only | false | true | 120 | 2.2 | unmeasured |  |  |  |  |  |  |  |  |  |  |  |  |  |  |  |  |  |  | No hardware available.
R1 |  | old-only | false | true | 10 | 2.2 | unmeasured |  |  |  |  |  |  |  |  |  |  |  |  |  |  |  |  |  |  | No hardware available.
R1 |  | old-only | false | true | 120 | 1.8 | unmeasured |  |  |  |  |  |  |  |  |  |  |  |  |  |  |  |  |  |  | No hardware available.
R1 |  | old-only | false | true | 10 | 1.8 | unmeasured |  |  |  |  |  |  |  |  |  |  |  |  |  |  |  |  |  |  | No hardware available.
R1 |  | old-only | true | false | 120 | 2.6 | unmeasured |  |  |  |  |  |  |  |  |  |  |  |  |  |  |  |  |  |  | No hardware available.
R1 |  | old-only | true | false | 10 | 2.6 | unmeasured |  |  |  |  |  |  |  |  |  |  |  |  |  |  |  |  |  |  | No hardware available.
R1 |  | old-only | true | false | 120 | 2.2 | unmeasured |  |  |  |  |  |  |  |  |  |  |  |  |  |  |  |  |  |  | No hardware available.
R1 |  | old-only | true | false | 10 | 2.2 | unmeasured |  |  |  |  |  |  |  |  |  |  |  |  |  |  |  |  |  |  | No hardware available.
R1 |  | old-only | true | false | 120 | 1.8 | unmeasured |  |  |  |  |  |  |  |  |  |  |  |  |  |  |  |  |  |  | No hardware available.
R1 |  | old-only | true | false | 10 | 1.8 | unmeasured |  |  |  |  |  |  |  |  |  |  |  |  |  |  |  |  |  |  | No hardware available.
R1 |  | old-only | true | true | 120 | 2.6 | unmeasured |  |  |  |  |  |  |  |  |  |  |  |  |  |  |  |  |  |  | No hardware available.
R1 |  | old-only | true | true | 10 | 2.6 | unmeasured |  |  |  |  |  |  |  |  |  |  |  |  |  |  |  |  |  |  | No hardware available.
R1 |  | old-only | true | true | 120 | 2.2 | unmeasured |  |  |  |  |  |  |  |  |  |  |  |  |  |  |  |  |  |  | No hardware available.
R1 |  | old-only | true | true | 10 | 2.2 | unmeasured |  |  |  |  |  |  |  |  |  |  |  |  |  |  |  |  |  |  | No hardware available.
R1 |  | old-only | true | true | 120 | 1.8 | unmeasured |  |  |  |  |  |  |  |  |  |  |  |  |  |  |  |  |  |  | No hardware available.
R1 |  | old-only | true | true | 10 | 1.8 | unmeasured |  |  |  |  |  |  |  |  |  |  |  |  |  |  |  |  |  |  | No hardware available.
R1 |  | tmp119-only | false | false | 120 | 2.6 | unmeasured |  |  |  |  |  |  |  |  |  |  |  |  |  |  |  |  |  |  | No hardware available.
R1 |  | tmp119-only | false | false | 10 | 2.6 | unmeasured |  |  |  |  |  |  |  |  |  |  |  |  |  |  |  |  |  |  | No hardware available.
R1 |  | tmp119-only | false | false | 120 | 2.2 | unmeasured |  |  |  |  |  |  |  |  |  |  |  |  |  |  |  |  |  |  | No hardware available.
R1 |  | tmp119-only | false | false | 10 | 2.2 | unmeasured |  |  |  |  |  |  |  |  |  |  |  |  |  |  |  |  |  |  | No hardware available.
R1 |  | tmp119-only | false | false | 120 | 1.8 | unmeasured |  |  |  |  |  |  |  |  |  |  |  |  |  |  |  |  |  |  | No hardware available.
R1 |  | tmp119-only | false | false | 10 | 1.8 | unmeasured |  |  |  |  |  |  |  |  |  |  |  |  |  |  |  |  |  |  | No hardware available.
R1 |  | tmp119-only | false | true | 120 | 2.6 | unmeasured |  |  |  |  |  |  |  |  |  |  |  |  |  |  |  |  |  |  | No hardware available.
R1 |  | tmp119-only | false | true | 10 | 2.6 | unmeasured |  |  |  |  |  |  |  |  |  |  |  |  |  |  |  |  |  |  | No hardware available.
R1 |  | tmp119-only | false | true | 120 | 2.2 | unmeasured |  |  |  |  |  |  |  |  |  |  |  |  |  |  |  |  |  |  | No hardware available.
R1 |  | tmp119-only | false | true | 10 | 2.2 | unmeasured |  |  |  |  |  |  |  |  |  |  |  |  |  |  |  |  |  |  | No hardware available.
R1 |  | tmp119-only | false | true | 120 | 1.8 | unmeasured |  |  |  |  |  |  |  |  |  |  |  |  |  |  |  |  |  |  | No hardware available.
R1 |  | tmp119-only | false | true | 10 | 1.8 | unmeasured |  |  |  |  |  |  |  |  |  |  |  |  |  |  |  |  |  |  | No hardware available.
R1 |  | tmp119-only | true | false | 120 | 2.6 | unmeasured |  |  |  |  |  |  |  |  |  |  |  |  |  |  |  |  |  |  | No hardware available.
R1 |  | tmp119-only | true | false | 10 | 2.6 | unmeasured |  |  |  |  |  |  |  |  |  |  |  |  |  |  |  |  |  |  | No hardware available.
R1 |  | tmp119-only | true | false | 120 | 2.2 | unmeasured |  |  |  |  |  |  |  |  |  |  |  |  |  |  |  |  |  |  | No hardware available.
R1 |  | tmp119-only | true | false | 10 | 2.2 | unmeasured |  |  |  |  |  |  |  |  |  |  |  |  |  |  |  |  |  |  | No hardware available.
R1 |  | tmp119-only | true | false | 120 | 1.8 | unmeasured |  |  |  |  |  |  |  |  |  |  |  |  |  |  |  |  |  |  | No hardware available.
R1 |  | tmp119-only | true | false | 10 | 1.8 | unmeasured |  |  |  |  |  |  |  |  |  |  |  |  |  |  |  |  |  |  | No hardware available.
R1 |  | tmp119-only | true | true | 120 | 2.6 | unmeasured |  |  |  |  |  |  |  |  |  |  |  |  |  |  |  |  |  |  | No hardware available.
R1 |  | tmp119-only | true | true | 10 | 2.6 | unmeasured |  |  |  |  |  |  |  |  |  |  |  |  |  |  |  |  |  |  | No hardware available.
R1 |  | tmp119-only | true | true | 120 | 2.2 | unmeasured |  |  |  |  |  |  |  |  |  |  |  |  |  |  |  |  |  |  | No hardware available.
R1 |  | tmp119-only | true | true | 10 | 2.2 | unmeasured |  |  |  |  |  |  |  |  |  |  |  |  |  |  |  |  |  |  | No hardware available.
R1 |  | tmp119-only | true | true | 120 | 1.8 | unmeasured |  |  |  |  |  |  |  |  |  |  |  |  |  |  |  |  |  |  | No hardware available.
R1 |  | tmp119-only | true | true | 10 | 1.8 | unmeasured |  |  |  |  |  |  |  |  |  |  |  |  |  |  |  |  |  |  | No hardware available.
R1 |  | both | false | false | 120 | 2.6 | unmeasured |  |  |  |  |  |  |  |  |  |  |  |  |  |  |  |  |  |  | No hardware available.
R1 |  | both | false | false | 10 | 2.6 | unmeasured |  |  |  |  |  |  |  |  |  |  |  |  |  |  |  |  |  |  | No hardware available.
R1 |  | both | false | false | 120 | 2.2 | unmeasured |  |  |  |  |  |  |  |  |  |  |  |  |  |  |  |  |  |  | No hardware available.
R1 |  | both | false | false | 10 | 2.2 | unmeasured |  |  |  |  |  |  |  |  |  |  |  |  |  |  |  |  |  |  | No hardware available.
R1 |  | both | false | false | 120 | 1.8 | unmeasured |  |  |  |  |  |  |  |  |  |  |  |  |  |  |  |  |  |  | No hardware available.
R1 |  | both | false | false | 10 | 1.8 | unmeasured |  |  |  |  |  |  |  |  |  |  |  |  |  |  |  |  |  |  | No hardware available.
R1 |  | both | false | true | 120 | 2.6 | unmeasured |  |  |  |  |  |  |  |  |  |  |  |  |  |  |  |  |  |  | No hardware available.
R1 |  | both | false | true | 10 | 2.6 | unmeasured |  |  |  |  |  |  |  |  |  |  |  |  |  |  |  |  |  |  | No hardware available.
R1 |  | both | false | true | 120 | 2.2 | unmeasured |  |  |  |  |  |  |  |  |  |  |  |  |  |  |  |  |  |  | No hardware available.
R1 |  | both | false | true | 10 | 2.2 | unmeasured |  |  |  |  |  |  |  |  |  |  |  |  |  |  |  |  |  |  | No hardware available.
R1 |  | both | false | true | 120 | 1.8 | unmeasured |  |  |  |  |  |  |  |  |  |  |  |  |  |  |  |  |  |  | No hardware available.
R1 |  | both | false | true | 10 | 1.8 | unmeasured |  |  |  |  |  |  |  |  |  |  |  |  |  |  |  |  |  |  | No hardware available.
R1 |  | both | true | false | 120 | 2.6 | unmeasured |  |  |  |  |  |  |  |  |  |  |  |  |  |  |  |  |  |  | No hardware available.
R1 |  | both | true | false | 10 | 2.6 | unmeasured |  |  |  |  |  |  |  |  |  |  |  |  |  |  |  |  |  |  | No hardware available.
R1 |  | both | true | false | 120 | 2.2 | unmeasured |  |  |  |  |  |  |  |  |  |  |  |  |  |  |  |  |  |  | No hardware available.
R1 |  | both | true | false | 10 | 2.2 | unmeasured |  |  |  |  |  |  |  |  |  |  |  |  |  |  |  |  |  |  | No hardware available.
R1 |  | both | true | false | 120 | 1.8 | unmeasured |  |  |  |  |  |  |  |  |  |  |  |  |  |  |  |  |  |  | No hardware available.
R1 |  | both | true | false | 10 | 1.8 | unmeasured |  |  |  |  |  |  |  |  |  |  |  |  |  |  |  |  |  |  | No hardware available.
R1 |  | both | true | true | 120 | 2.6 | unmeasured |  |  |  |  |  |  |  |  |  |  |  |  |  |  |  |  |  |  | No hardware available.
R1 |  | both | true | true | 10 | 2.6 | unmeasured |  |  |  |  |  |  |  |  |  |  |  |  |  |  |  |  |  |  | No hardware available.
R1 |  | both | true | true | 120 | 2.2 | unmeasured |  |  |  |  |  |  |  |  |  |  |  |  |  |  |  |  |  |  | No hardware available.
R1 |  | both | true | true | 10 | 2.2 | unmeasured |  |  |  |  |  |  |  |  |  |  |  |  |  |  |  |  |  |  | No hardware available.
R1 |  | both | true | true | 120 | 1.8 | unmeasured |  |  |  |  |  |  |  |  |  |  |  |  |  |  |  |  |  |  | No hardware available.
R1 |  | both | true | true | 10 | 1.8 | unmeasured |  |  |  |  |  |  |  |  |  |  |  |  |  |  |  |  |  |  | No hardware available.

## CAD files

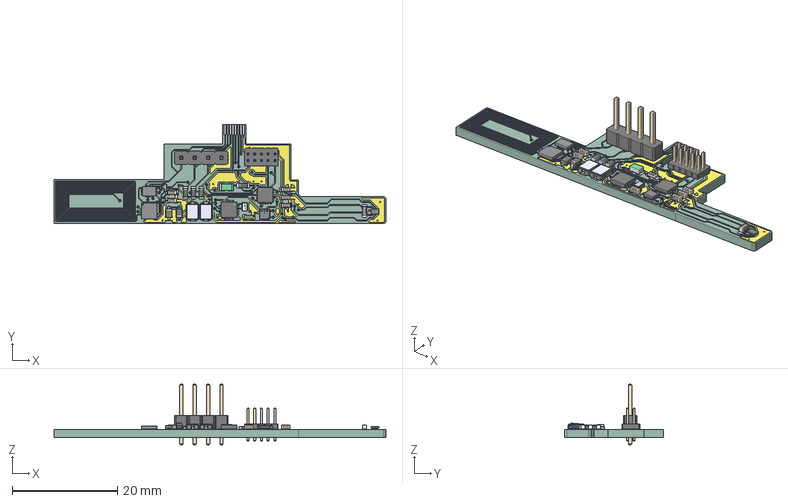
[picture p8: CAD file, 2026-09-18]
NFC_harvester_battery_free/hardware/exports/densor_nfc_v2.step
63.0 x 18.8 x 11.5 mm
ST_UFQFPN_20_3x3mm_P05mm
C_0603_1608Metric x 7
PinHeader_2x05_P127mm_Vertical
STM Logo
R_0603_1608Metric x 4
CPH3225A x 2
D_SOD-323
AK-21.0003.01
BODY-SON1
QFN-16-1EP_3x3mm_P0.5mm_EP1.7x1.7mm
ABS05W
D_SOD_323F
PinHeader_1x04_P254mm_Vertical
ST25DV04K-JFR6D3
densor_nfc_v2_copper
densor_nfc_v2_pad
densor_nfc_v2_via
densor_nfc_v2_PCB

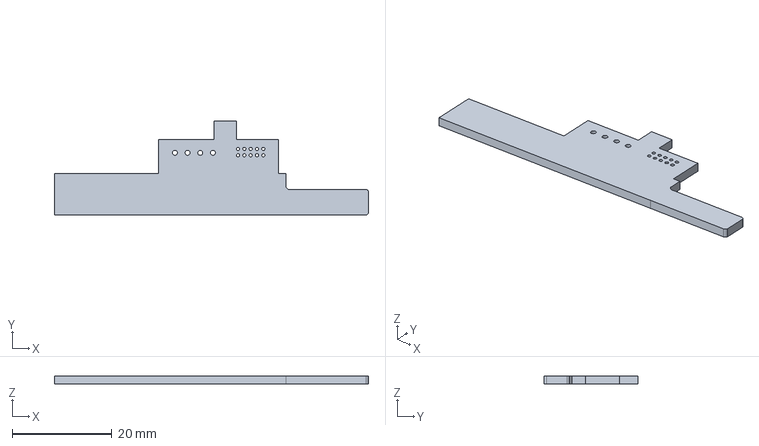
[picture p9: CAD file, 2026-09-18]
NFC_harvester_battery_free/hardware/exports/board-1.6mm.step
63.0 x 18.8 x 1.60 mm

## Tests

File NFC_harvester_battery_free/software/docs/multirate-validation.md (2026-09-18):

# R2/R3 validation record

Documentation verification on **2026-09-18**, against source commit
`e7071cc` with documentation edits only. Commands below were run from the
repository root. Tests exercise software and simulated device state; no physical
Densor board, NFC exchange or phone was tested in this documentation update.

## Checks run

| Check | Result |
| --- | --- |
| `make -C NFC_harvester_battery_free/software/DentalSensor_StorageProject -j4 REVISION=<variant>` for R2a/R2b/R3a/R3b | All four targets passed; existing objects were up to date and manifests refreshed |
| `python3 NFC_harvester_battery_free/software/tools/test_multirate.py` | All four logger/scheduler combinations passed under address/undefined-behavior sanitizers |
| Multirate board entry point with fake HAL | 85 scenarios per variant, 340 total, passed |
| C writer → Java decoder | 360 full EEPROM images passed, covering 15 masks, three capacities, two fixture kinds and four variants |
| Java requests → C firmware → Java decoding | 360 allocation requests committed and decoded successfully |
| Fixed record vectors and bundled Android/debug fixtures | Matched firmware writer output |
| `python3 NFC_harvester_battery_free/software/tools/test_r1.py` | R1 storage/configuration/TMP119 tests, 110 board checks, 45 C-produced recordings and golden vectors passed |
| Historical CSV reconstruction | 210 samples agreed between legacy and R1 decoding; TMP119 absent |

Multirate core tests cover masks, mixed and uniform schedules, duplicate/early/
late wakes, delay, phase/sequence rollover, full memory, missing sensors, invalid
allocations and requests, retained-state loss, pointer ambiguity and corruption.
Injected byte-write failures exercise 109 transaction, 726 initialization and
104 Stop boundaries per partitioned variant; shared variants exercise 89,
696 and 89 respectively. These are simulated failure boundaries, not physical
power-cut measurements.

Generated host images and executables are under `software/build/multirate-tests/`;
R1 results are under `software/build/tests/`. The multirate fixture check
does not overwrite checked fixtures unless explicitly given `--update-fixtures`.

## Firmware memory

The variant manifests reported the following allocations for the checked build
outputs. These are binary/linker measurements, not runtime stack measurements.

| Variant | Flash load extent (bytes) | Static SRAM (bytes) | RTC retained RAM (bytes) |
| --- | ---: | ---: | ---: |
| R2a, shared/FSM | 12,348 | 348 | 64 |
| R2b, shared/RTC | 12,356 | 348 | 64 |
| R3a, partitioned/FSM | 12,780 | 348 | 64 |
| R3b, partitioned/RTC | 12,764 | 348 | 64 |

The physical linker limits remain 16,384 bytes Flash and 2,048 bytes SRAM.
Heap/stack reservations remain 512/1,024 bytes. Static SRAM excludes those
reservations; inspect the linker map and compiler `.su` output together before
estimating margin. Runtime stack high-water and interrupt margin are unmeasured.
All variants reserve 168 EEPROM metadata bytes.

## Android evidence and remaining work

The host checks above compile and execute the production Java decoder; they
do not build an APK or exercise Android's NFC transport. The complete
`build_multirate.py` packaging/Gradle workflow was documented from source but
was not rerun for this documentation change.

Existing [R1 phone checks](android-phone-tests.md) apply to the recorded R1 APK.
Later [synthetic EEPROM export/import evidence](../../../logs/codex/01a0b51a-3652-72d2-a6a2-569deb55c310/qa/eeprom-export-validation.md)
records multirate debug-app checks on the S21 FE. That report contains older
R2/R3 labels; identify its cases by the stated storage/timing pair and image
hash, and use the current names in the [overview](../README.md). Neither report
is a fresh phone test of this checkout.

Before treating a candidate as hardware-validated, measure actual sensor
availability, RTC timing/drift, startup delay, acquisition duration, NFC/MCU
contention, power-loss behavior, EEPROM/RTC retention and migration on the
board. Measure energy and stack/heap use, including the voltage cases in the
[run template](../measurements/run-results.csv). TMP119 nonvolatile startup
provisioning and power-cycle readback remain pending. Verify the actual APK
signer and upgrade compatibility, and bind any release to exact source and
artifact hashes. Current build manifests explicitly report `release_ready=false`.

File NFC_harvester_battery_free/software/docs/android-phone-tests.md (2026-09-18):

# R1 Android phone checks

Result on 2026-09-18 for simplified R1: **6 tests passed**; release installation
and launch passed. Settings/reset controls and temperature plots were inspected.
The [result JSON](../measurements/android-phone-results.json) identifies the exact
APKs and limitations; [instrumentation output](../measurements/android-instrumentation-results.txt)
records the run.

Device: Samsung Galaxy S21 FE (`SM-G990B`), Android 16 / API 36, connected over
USB. Testing uses the ADB coordination skill's exclusive claim. Android Agent
Lab registered the Gradle project at `source_ST25NFCApplication_V3_9`.

The release variant has application ID `com.st.st25nfc`, version code 28 and
version `3.10.2-r1`. Installation and launch succeeded on this phone. Reinstalling
with the same local signer also succeeded without clearing application data.
This does not establish compatibility with an old deployed APK's signing key;
that APK/key was unavailable. The local debug signing configuration remains a
publication limitation.

The `phoneTest` build uses the same release sources and package/signing identity,
plus a fixture activity and an in-memory `NFCTag`. The fixture activity is absent
from the release APK and says **TEST FIXTURE — no NFC hardware**. The companion
instrumentation APK runs these six tests:

1. Old-only, TMP119-only and both-temperature binary decoding in Android's Java
   runtime, including independent fields.
2. Applying settings to a running recording in one request while keeping active
   settings/data unchanged until firmware acknowledgement, including a 59-minute startup delay.
3. Separate source-labelled temperature plots, including nonzero display bounds
   for a recording containing just one sample.
4. Resetting with the current settings, including the one-time startup delay, without Start/Stop controls.
5. Writing a pending configuration without changing the displayed active
   configuration or pretending the MCU acknowledged it; incomplete commit markers
   remain inactive.
6. Rendering the [210-sample historical CSV reconstruction](../tests/HISTORICAL_DATA.md),
   comparing legacy/R1 readings and keeping TMP119 absent.

NFC read/write operations in these tests use simulated memory. RF exchange,
actual firmware acknowledgement, sensor acquisition, host/MCU contention and
board power cycles remain unmeasured. A UI test is not evidence for those gates.
The unrelated upstream Type2 instrumentation suite is excluded because its ST
test-rig dependencies (`AndroidHelper` and `Type2Tests`) are not in this checkout.

Build the candidate first, then from the Gradle root use the JDK 17 selected by
`JAVA_HOME` and the scoped SDK created by `build_r1.py`:

```sh
ANDROID_HOME=../build/android-sdk \
ANDROID_SDK_ROOT=../build/android-sdk \
bash gradlew --no-daemon :app:assemblePhoneTest :app:assemblePhoneTestAndroidTest
```

Claim the explicitly selected device with `adb_coord.py` following the
ADB coordination skill. Store its returned JSON privately outside the repository
with mode `0600`; do not use another thread's claim or a human reservation. From
the repository root, supply the relative paths to that claim and your installed
coordinator script:

```sh
python3 NFC_harvester_battery_free/software/tools/test_android_phone.py \
  --claim-file ../private/this-thread-claim.json \
  --coordinator path/to/adb_coord.py
```

The helper wraps every device operation through the coordinator, runs the six
tests and copies screenshots. It restores and launches the release APK after
testing, including on failure. Evidence is in `build/phone-r1`: a result JSON
with APK hashes, instrumentation output, a token-free ADB transcript and screen
captures. A copied measurement JSON records the particular APKs tested; a later
build must not inherit those results if its APK hash differs. Release the claim
when finished.

## Debug mode checks

Six Robolectric tests (Android API 35) exercise the debug activity with the real
R1 fragments: pending interval/startup-delay writes and recreation; invalid
settings leaving memory unchanged; document-picker import/export and historical
plots; legacy write rejection; density/truncation/bounds checks; and reset keeping
the active startup delay. The debug-only example assets match the C-produced and
historical reconstruction fixtures checked by `test_r1.py`.

The debug APK was also installed on the S21 FE as `com.st.st25nfc.dbg`, alongside
the release APK. Main screen → Debug mode, Settings/Data switching, and the startup
delay control passed the device smoke check; screenshots were inspected. See
[debug phone results](../measurements/android-debug-phone-results.json). Import and
export were exercised by Robolectric; physical RF and MCU timing remain unmeasured.

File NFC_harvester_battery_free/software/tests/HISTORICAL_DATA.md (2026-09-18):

# Historical recordings used in R1 tests

This checkout contains **54 Densor CSV recordings** in
[`data/experiments/labeled_data`](../../data/experiments/labeled_data),
plus their session metadata in
[`index.json`](../../data/experiments/index.json).
The original NFC `.bin` dumps are absent. The retainer data-dumps README lists
recordings, but the binaries are absent.

The regression fixture uses
[`2024-04-05-p1-e-1.csv`](../../data/experiments/labeled_data/2024-04-05-p1-e-1.csv):
210 rows containing LIS2DW12 temperature, photodiode, three acceleration axes
and supply voltage at a one-second interval. The source contains **no TMP119**.

These CSV values are processed data. The historical `data_master.py` enables
compensation by default; `plot_readings.py` subtracts
`(supply_V * 10 - 25) * 0.14` from temperature and converts photodiode ADC codes
to millivolts with `raw * supply_V * 1000 / 4095`. Acceleration columns are
signed raw codes in these CSVs, despite an old reader docstring describing g.

[`replay_csv_fixture.py`](../tools/replay_csv_fixture.py) reverses those two
documented transformations. Every inverse result must land on its sensor's
integer-code grid within 1e-6 and satisfy the code bounds; otherwise generation
fails. It sets the old temperature's unavailable low four bits to zero and does
not generate TMP119 readings. It produces:

- A **reconstructed legacy fixture**, retaining the source interval and epoch
  but using a pointer for the CSV's 210-row prefix (2,109 bytes).
- A **reconstructed R1 fixture**, written through the actual C session/logger
  code with mask `0x0D`, 12-byte records and a 2,648-byte final pointer. It uses a
  simulated 8,192-byte memory; this is not proof of the populated hardware's
  density. R1 nominal elapsed times start at zero and do not claim a measured
  new session epoch.
- A provenance JSON file recording input hashes, transforms, lengths and
  limitations, generated in `build/tests` and copied into the candidate bundle.

The source index reports a 2,599-byte original pointer (259 records), while the
labelled CSV has only 210. The remaining 49 samples and original EEPROM bytes
cannot be recovered from this CSV. These fixtures are **reconstructions**, not
real NFC dumps, R1 acquisitions, measured TMP119 data or an in-place migration.

The host suite compares every reconstructed reading between the legacy and R1
Java decoders, checks representative values independently, and verifies that
the checked-in Android test assets match fresh output from the C writer. The
phone test renders the reconstructed R1 trace and verifies that the TMP119 plot
stays hidden. Separate synthetic fixtures exercise TMP119-only/both modes and
negative result codes.

Regenerate and check with:

```sh
python3 NFC_harvester_battery_free/software/tools/test_r1.py
python3 NFC_harvester_battery_free/software/tools/replay_csv_fixture.py
```

This tooling writes only local test files. Device migration remains
export-and-new-session; raw legacy records cannot be appended directly to an
R1 recording.

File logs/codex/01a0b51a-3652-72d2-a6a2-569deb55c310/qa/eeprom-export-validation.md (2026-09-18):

# Sampling lab EEPROM export validation

Date: 2026-09-18. All existing thread logs were preserved; this report and the
phone screenshots are additional evidence.

## Host checks

- 19 Node tests passed, including the unchanged lab-preview checks and nine
  firmware test groups. [Final output](eeprom-host-tests-authoritative.txt).
- All five complete canonical golden images matched their supplied bytes and
  SHA-256 values. Standard CRC8/CRC16 vectors passed.
- 225 combinations (R1/R2a/R2b/R3a/R3b × all 15 masks × 512/2048/8192 bytes)
  decoded successfully using actual Java source from authoritative commit
  `48a8f137aa9dba162e88bdad67b549bfde232d40`.
- Decoded source values after quantization, missing fields, supply, timestamps,
  counts, pointers, CSV revision labels and complete-session status matched.
- Tests cover fractional source origin, unequal temperature periods, empty
  ticks, exact fits, stopping the whole wake before capacity overflow, erased
  tails, negative values, rounding ties, signed limits, invalid periods/LCM,
  disabled sensors and missing due values. CRC/metadata/pointer/padding damage
  is rejected. Python independently extracts a firmware ZIP and its sidecar.
- Both Python HTTP tests and JavaScript syntax checks passed. The local app
  returned HTTP 200 at `http://127.0.0.1:8766/`.

The test compiles a read-only copy of the four Java sources obtained with
`git show` into `software/build/sampling-lab-export-check/`. Another thread
changed the working-tree Android CSV labels during validation; the initial
[working-tree run](eeprom-host-tests.txt) retained here records that label
mismatch. Pinning the oracle to the specified commit restored reproducible
contract testing without reverting those changes. Generated binaries, JSON
sidecars and `matrix-summary.json` are in that build directory.

## Android debug import

Device: S21 FE, SM-G990B, USB serial `RFCT10E2EYM`.
Used the ADB coordinator with an exclusive claim and released it after testing.
Installed the existing `com.st.st25nfc.dbg` debug APK, version
3.11.0-multirate / code 29, with `install -r`; no uninstall or app-data clearing.
The release package was not changed.

Both inputs came from the real CSV, using source window `[0,1800)`, phase 0,
periods `[120,60,30,10]` in firmware order, and 2048-byte capacity. Source SHA-256:
`45f69ea6012272d07618c5e81aa3c703b421e86ef5b9b844750170d319fabd0f`.

| Imported image | Counts: temp1, temp2, light, accel | Last elapsed | Stop reason |
| --- | --- | --- | --- |
| sampling-lab-r3a-v5-2048.bin | 15, 30, 60, 180 | 1790 s | window-end |
| sampling-lab-r3b-v5-2048.bin | 13, 25, 50, 148 | 1470 s | capacity; next wake 1480 s omitted |

- R3a image SHA-256:
  `2abb2b2dff96006077943468dd952b3ee417549301c3e479136dc2976a088b46`.
  Final pointers `[228,352,596,2040]`.
- R3b image SHA-256:
  `488367dfe577864919e17e5c8e5fc2c891f5243e0d1a16953f9f216490f011f6`.
  Final pooled pointer `2044`.

Opened each image through **Debug mode → Open .bin → Android document picker**,
then inspected **Data**. Both reported **Loaded 2048 B**, the correct storage
and RTC revision, **Stopped, acknowledged checkpoint**, and **Complete recording**.
Separate temperature values and 2.6 V supply were shown.

[Partitioned R3a screenshot](eeprom-r3a-import.png) ·
[Shared R3b screenshot](eeprom-r3b-import.png).

The phone was left in the debug Data screen with the shared synthetic image;
the two import files remain in Downloads. No live NFC, firmware execution,
hardware sensor, power or energy claim follows from these checks. Web browser
interaction/visual QA was unavailable in this session.

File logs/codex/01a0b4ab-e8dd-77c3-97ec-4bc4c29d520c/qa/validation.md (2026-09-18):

# Densor debug settings validation

Implemented a debug-only virtual NFC tag using writable 8 KiB EEPROM memory.
The existing settings fragment now reads, writes, reloads, and verifies settings
against either the physical tag or the debug tag.

## Samsung S21 FE (requested final device)

Repeated the complete import/update/validation/export/reopen workflow on the
physical Samsung SM-G990B, Android 16, serial RFCT10E2EYM, after its previous
claim was released. Installed the debug APK without clearing app data.

- Imported the separate synthetic file Download/densor-sample-test-01a0b4ab.bin.
- Read 45 seconds, changed to 20 minutes, and verified successful read-back.
- Rejected 60; Reload restored the stored 20 minutes.
- Exported Download/densor-s21-20min-01a0b4ab.bin (8192 bytes).
- Pulled the export and verified that only byte 0x05 changed: 0x45 to 0xA0.
- Reopened the exported file and confirmed 20 minutes remained selected.
- Inspected the phone screenshot and checked AndroidRuntime logs for the app
  process; no runtime errors were reported.
- Left the debug screen open and released the cooperative device claim.

Evidence: [S21 FE screenshot](s21-fe-debug-20-minutes.png),
[S21 FE exported dump](densor-s21-exported.bin).

The earlier Docker emulator was stopped with its Android data preserved.
The Android Agent Lab desktop app remains open with the project open request
sent; physical-phone control used its shared ADB coordination workflow.

## Earlier Android Agent Lab emulator check

Used the Android Agent Lab Docker emulator, Android 16 / API 36.1,
serial 127.0.0.1:15555. Registered the Gradle root with the desktop app using
android-agent-lab; the open request was acknowledged. GUI project selection was
not independently inspected. Device actions used the shared ADB coordinator.

Confirmed on the running app:

- Launch without NFC hardware and enter Debug mode.
- Import densor-input.bin through Android's document picker; read 45 seconds.
- Change to 20 minutes and Update; successful read-back shown.
- Enter 60; validation rejects it. Reload restores the stored value of 20 minutes.
- Export densor-debug.bin through the system file picker; output is 8192 bytes.
- Compare input/output: only byte 0x05 changes, from 0x45 to 0xA0.
- Reopen the exported file; 20 minutes is selected.
- No AndroidRuntime errors for the app process were reported during this session.

Screenshot: [Reopened 20-minute dump](densor-debug-20-minutes.png).
Binary fixtures: [input](densor-input.bin), [exported](densor-exported.bin).
Fixtures are synthetic test data, not measurements from a real sensor.

## Automated checks

13 tests passed: 10 EEPROM/settings tests and 3 Robolectric Android UI tests.
Coverage includes all 0–59 interval encodings in both units, startup-delay flags,
reserved-bit and measurement-byte preservation, invalid input and dump lengths,
memory bounds, silent dropped writes, document import/export, and activity
recreation.

Debug and release APK builds succeeded. The release APK does not contain the
DensorDebugActivity class. Lint reports no errors in the new settings/debug
sources; the repository still has pre-existing lint findings, including pending
intent flags. Lint is configured by the existing project not to abort the build.

The installed Android SDK also contains 37.1 platforms that this older Android
Gradle plugin's lint cannot parse. Validation used a temporary SDK overlay with
Android 33 and the installed build tools; the SDK and project compile target
were not modified. Ordinary assembleDebug also succeeds with the normal SDK.

The host's native emulator crashes during startup. The successful device tests
above used Android Agent Lab instead. No physical Densor sampling timing, NFC
radio behavior, or energy harvesting was tested.

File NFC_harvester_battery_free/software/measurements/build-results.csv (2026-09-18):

release | status | source_revision | source_dirty | compiler | flash_load_bytes | flash_free_bytes | sram_static_bytes | heap_reserved_bytes | stack_reserved_bytes | sram_alignment_bytes | sram_linked_bytes | sram_unreserved_bytes | peak_stack_bytes | peak_heap_bytes | stack_margin_bytes | rtc_ram_bytes | physical_eeprom_bytes | metadata_bytes | old_temperature_supported | tmp119_temperature_supported | android_version | android_apk_bytes | android_install_upgrade
R1 | software candidate; unmeasured hardware gates | e8e86be09119d27d09da858fc65652124fcd5f78 | false | arm-none-eabi-gcc (Fedora 15.2.0-4.fc44) 15.2.0 | 13504 | 2880 | 312 | 512 | 1024 | 0 | 1848 | 200 |  |  |  | 0 |  | 128 | yes | yes | 3.10.2-r1 | 8775175 | S21 FE install/launch and same-signer reinstall passed; historical deployed upgrade unverified

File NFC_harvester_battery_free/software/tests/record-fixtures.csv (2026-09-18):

name | mask | supply | old_raw | tmp119_raw | pd_raw | accel_x | accel_y | accel_z | record_hex
old_positive | 1 | 8 | 3072 |  |  |  |  |  | 08000c00
old_negative | 1 | 4 | -7680 |  |  |  |  |  | 0400e200
tmp_positive | 2 | 8 |  | 4736 |  |  |  |  | 08801200
tmp_negative | 2 | 0 |  | -128 |  |  |  |  | 0080ff00
both_signed | 3 | 15 | -7680 | -128 |  |  |  |  | 0f00e280ff000000
accel_only | 8 | 255 |  |  |  | 16384 | -16384 | 0 | ff004000c0000000
all | 15 | 8 | 3072 | 4736 | 2048 | 16384 | -16384 | 0 | 08000c80120008004000c00000000000

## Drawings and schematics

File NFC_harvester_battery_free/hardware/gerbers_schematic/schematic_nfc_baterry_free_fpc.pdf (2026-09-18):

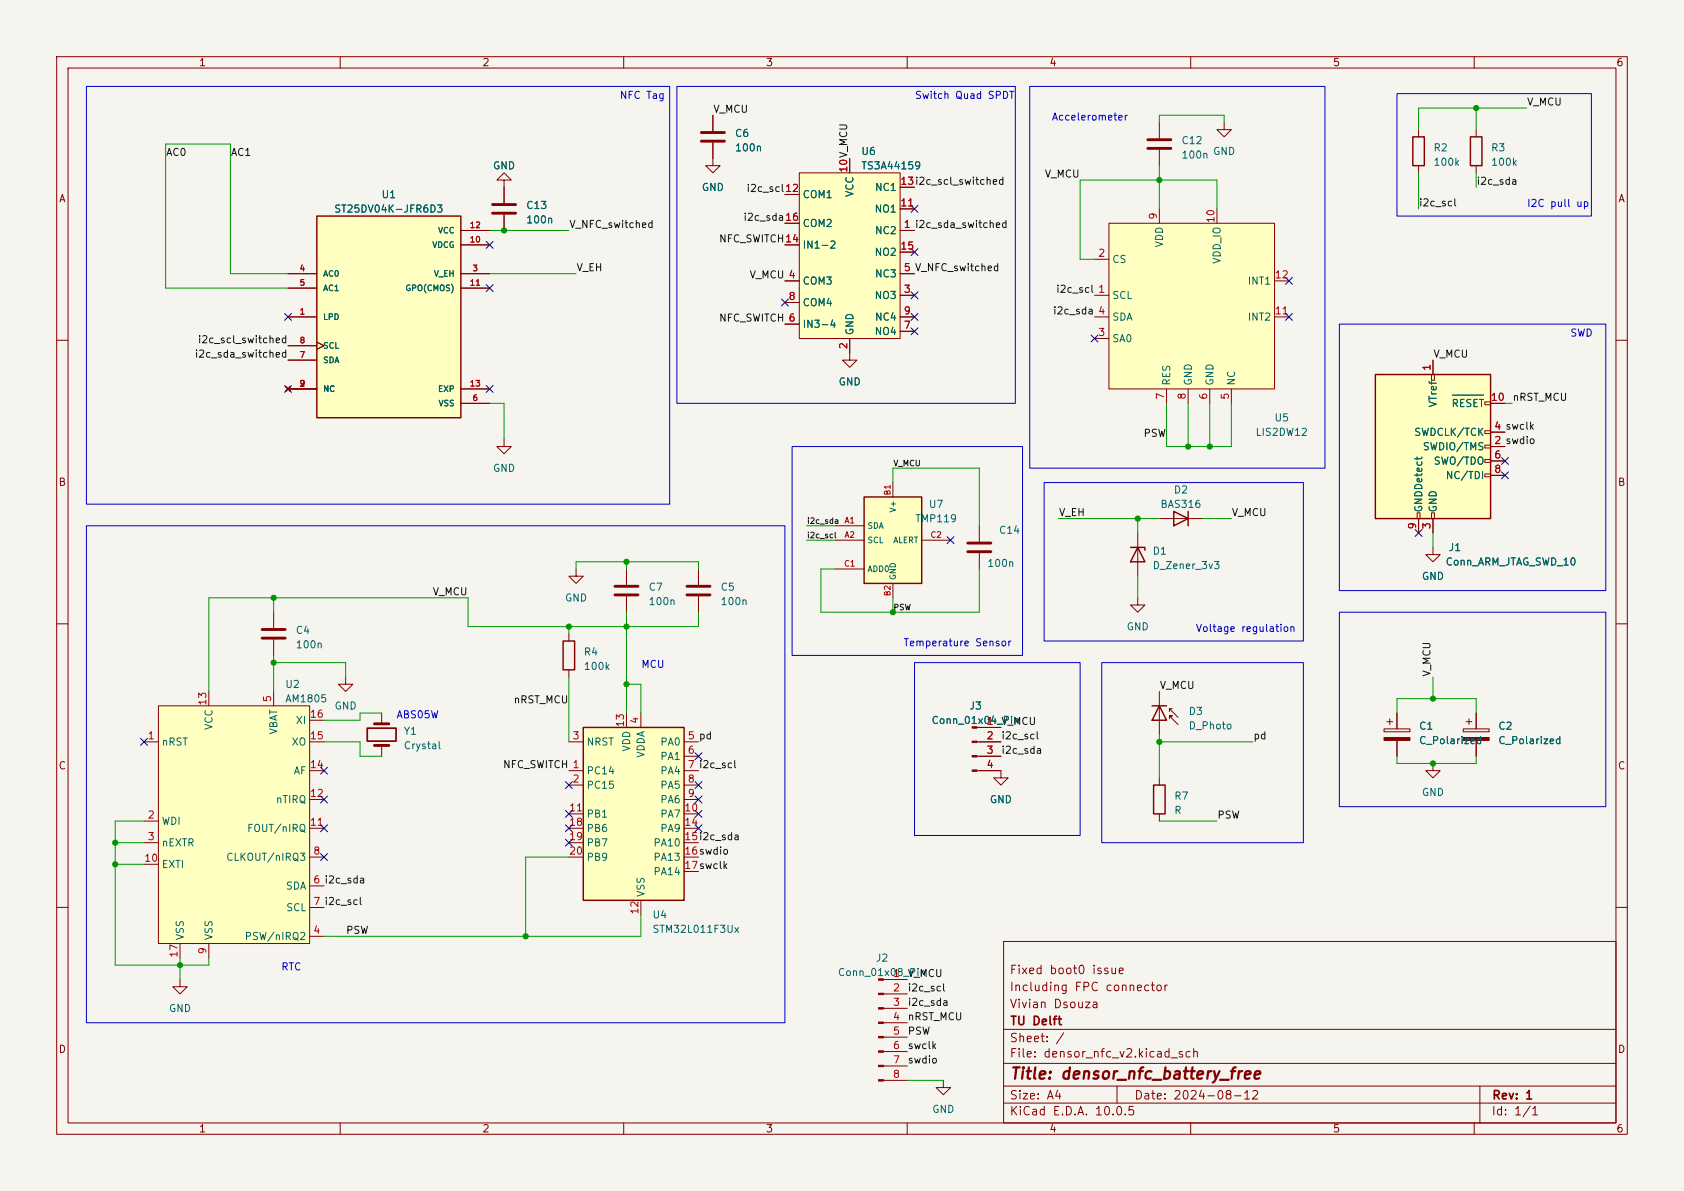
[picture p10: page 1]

Size: A4 | Rev: 1
KiCad E.D.A. 10.0.5 | Id: 1/1

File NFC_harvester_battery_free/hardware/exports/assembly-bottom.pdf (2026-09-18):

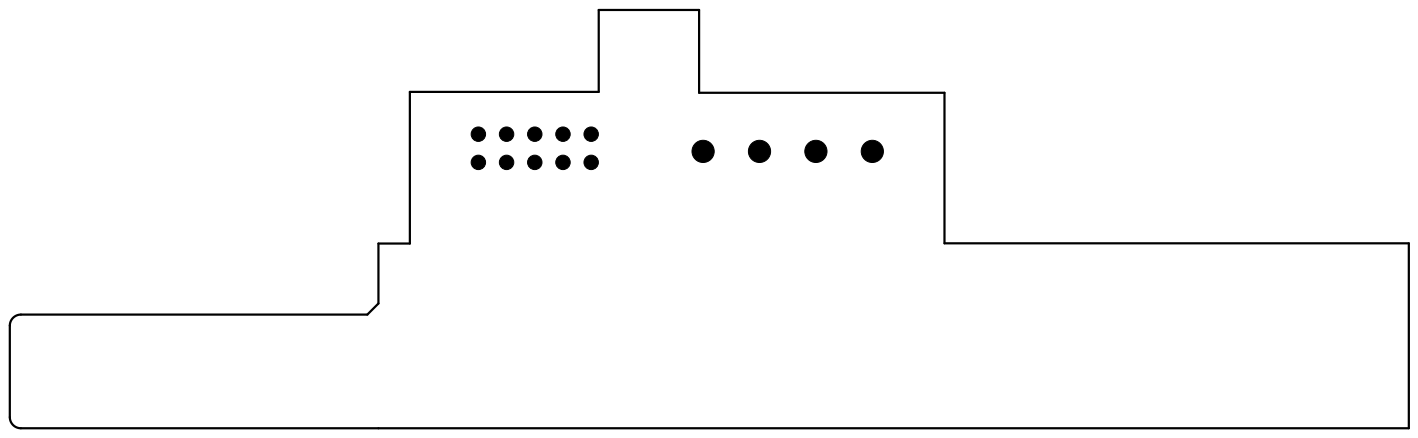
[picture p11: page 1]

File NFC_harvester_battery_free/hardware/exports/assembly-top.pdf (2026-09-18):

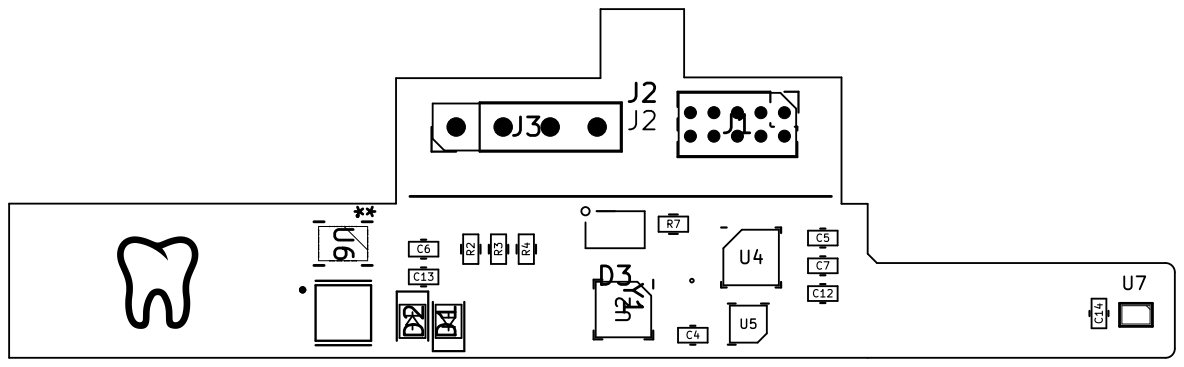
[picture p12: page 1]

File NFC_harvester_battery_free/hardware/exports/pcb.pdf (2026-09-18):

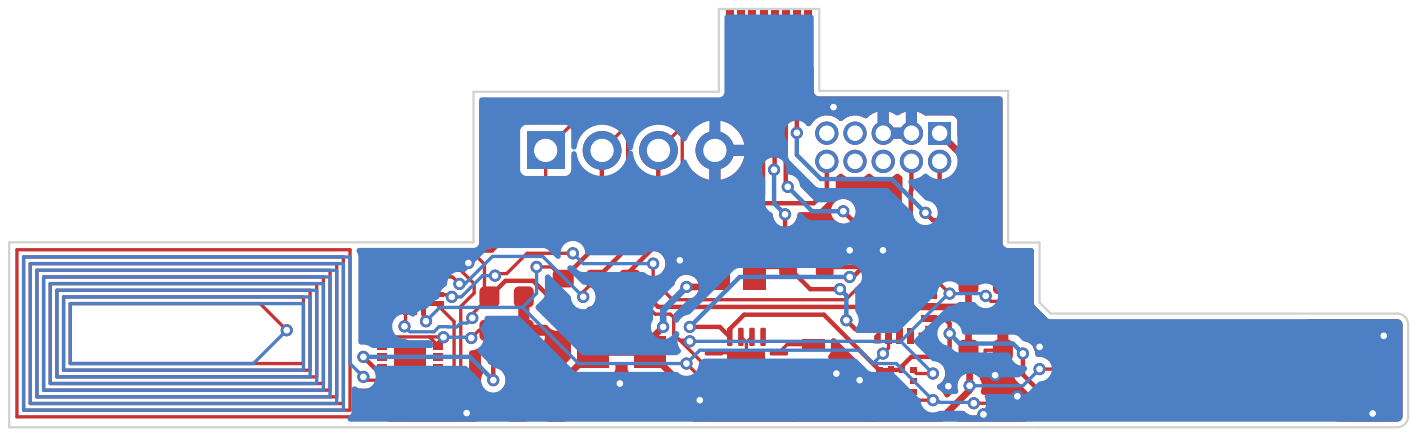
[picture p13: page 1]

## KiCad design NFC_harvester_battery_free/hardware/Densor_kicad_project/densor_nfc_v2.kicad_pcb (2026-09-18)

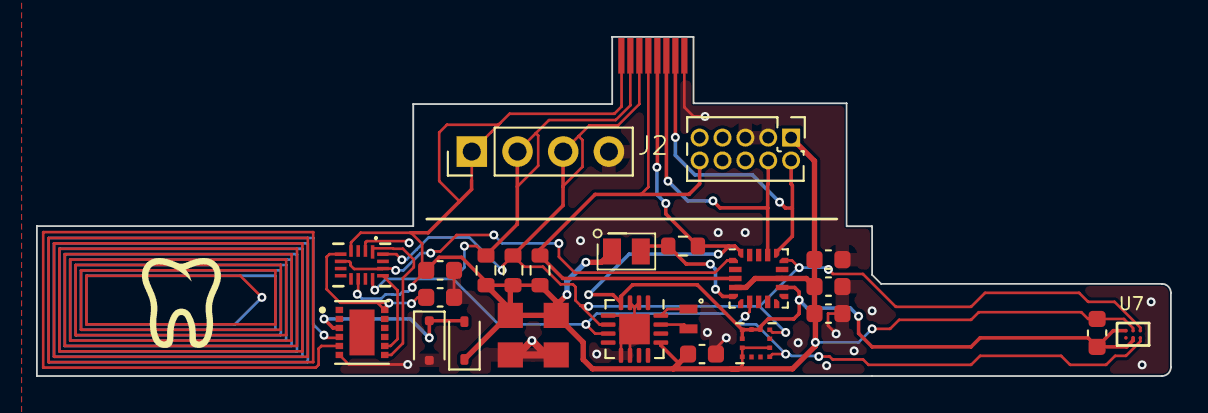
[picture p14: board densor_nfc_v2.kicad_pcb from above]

Board: 2 copper layers, 63.0 x 18.8 mm, 26 parts (0 on the bottom side), 17 nets.

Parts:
C1, C2: C_Polarized; CPX3225A
C4, C5, C6, C7, C12, C13, C14: 100n; C_0603_1608Metric
D1: D_Zener_3v3; D_SOD-323F
D2: BAS316; D_SOD-323
D3: D_Photo; pd_vemd1060x01
J1: Conn_ARM_JTAG_SWD_10; PinHeader_2x05_P1.27mm_Vertical
J2: Conn_01x08_Pin; fpc_503480-0800
J3: Conn_01x04_Pin; PinHeader_1x04_P2.54mm_Vertical
R2, R3, R4: 100k; R_0603_1608Metric
R7: R; R_0603_1608Metric
U1: ST25DV04K-JFR6D3; PSON50P300X300X60-13N
U2: AM1805; QFN-16-1EP_3x3mm_P0.5mm_EP1.7x1.7mm
U4: STM32L011F3Ux; ST_UFQFPN-20_3x3mm_P0.5mm
U5: LIS2DW12; Kionix_LGA-12_2x2mm_P0.5mm_LayoutBorder2x4y
U6: TS3A44159; RSV16
U7: TMP119; DSBGA6_YBG_TEX
Y1: Crystal; ABS05W_Crystal

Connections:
/AC0: U1.4 (AC0), U1.5 (AC1)
/NFC_SWITCH: U4.1 (PC14), U6.6 (IN3-4), U6.14 (IN1-2)
/PSW: C14.2, J2.5, R7.2, U2.4 (PSW/nIRQ2), U4.12 (VSS), U4.20 (PB9), U5.5 (NC), U5.6 (GND), U5.7 (RES), U5.8 (GND), U7.B2, U7.C1
/V_EH: D1.1 (K), D2.2 (A), U1.3 (V_EH)
/V_MCU: C1.1, C2.1, C4.1, C5.2, C6.1, C7.2, C12.2, C14.1, D2.1 (K), D3.1 (K), J1.1 (VTref), J2.1, J3.1, R2.1, R3.1, R4.1, U2.13 (VCC), U4.4 (VDDA), U4.13 (VDD), U5.2 (CS), U5.9 (VDD), U5.10 (VDD_IO), U6.4 (COM3), U6.10 (VCC), U7.B1
/V_NFC_switched: C13.2, U1.12 (VCC), U6.5 (NC3)
/i2c_scl: J2.2, J3.2, R2.2, U2.7 (SCL), U4.7 (PA4), U5.1 (SCL), U6.12 (COM1), U7.A2
/i2c_scl_switched: U1.8 (SCL), U6.13 (NC1)
/i2c_sda: J2.3, J3.3, R3.2, U2.6 (SDA), U4.15 (PA10), U5.4 (SDA), U6.16 (COM2), U7.A1
/i2c_sda_switched: U1.7 (SDA), U6.1 (NC2)
/nRST_MCU: J1.10 (~RESET), J2.4, R4.2, U4.3 (NRST)
/pd: D3.2 (A), R7.1, U4.5 (PA0)
/swclk: J1.4 (SWDCLK/TCK), J2.6, U4.17 (PA14)
/swdio: J1.2 (SWDIO/TMS), J2.7, U4.16 (PA13)
GND: C1.2, C2.2, C4.2, C5.1, C6.2, C7.1, C12.1, C13.1, D1.2 (A), J1.3 (GND), J1.5 (GND), J2.8, J3.4, U1.6 (VSS), U2.2 (WDI), U2.3 (nEXTR), U2.5 (VBAT), U2.9 (VSS), U2.10 (EXTI), U2.17 (VSS), U6.2 (GND)
unnamed: U2.16 (XI), Y1.1
unnamed: U2.15 (XO), Y1.2

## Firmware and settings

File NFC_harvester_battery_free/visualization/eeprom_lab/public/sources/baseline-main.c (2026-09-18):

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
/* Includes ------------------------------------------------------------------*/
#include "main.h"

/* USER CODE BEGIN Includes */
#include <stdbool.h>

/* USER CODE END Includes */

/* USER CODE BEGIN PD */
#define NFC_ADDR 					0xA6
#define ACCEL_ADDR 					0x32
#define DEBUG_TERMINAL				0xAA
#define AM1805_ADDR 				0xD2

#define ACCEL_TEMP_BASE				0x0D
#define ACCEL_CONTROL1				0x20
#define ACCEL_OUT_X_L				0x28

#define RTC_SECONDS                 0x01
#define RTC_SECONDS_ALARM           0x09
#define RTC_MINUTES					0x02
#define RTC_MINUTES_ALARM			0x0A
#define RTC_OSCILLATOR_CONTROL      0x1C
#define RTC_CONFIGURATION_KEY       0x1F
#define RTC_CONTROL2                0x11
#define RTC_INTMASK                 0x12
#define RTC_COUNTDOWN_TIMER_CONTROL 0x18
#define RTC_STATUS                  0x0F
#define RTC_SLEEP_CONTROL			0x17

#define SENSOR_ENABLE_REG			0x00
#define TIMESTAMP_REG				0x01
#define RTC_INTERVAL_REG			0x05
#define STARTUP_DELAY_REG			0x06
#define MEM_POINTER_REG				0x07

#define MEMORY_SIZE 				8192

#define VREF_CAL_ADDR				((uint16_t*) (0x1FF80078)) // Datasheet p.51
#define VREF_CAL_VDDA				3000 // Datasheet p.51

#define DEBUG_TEST 					false
#define CHARGE_MODE					true

/* USER CODE END PD */

ADC_HandleTypeDef hadc;

I2C_HandleTypeDef hi2c1;

/* USER CODE BEGIN PV */

// Pointer to current memory position to write to.
uint16_t memPointer = 9;
// Zero value. Used for wiping memory.
uint8_t zero = 0;
// Holder for the interval set on the RTC. Default is 10 seconds.
uint8_t rtcInterval = 0x10;

// Holder for the value in the seconds register on the RTC at boot.
uint8_t bootSeconds = 0x60;
// Holder for the value in the minutes register on the RTC at boot.
uint8_t bootMinutes = 0x60;
// Holder for the startup delay.
uint8_t startupDelay = 0x00;

// Holder for boolean that determines which clock source the RTC should use. If true uses internal RC clock, if false, uses external XT crystal.
bool rcEnable = true;
// Holders for booleans that determine which sensors are turned on and off.
bool tempEnable = false;
bool moistureEnable = false;
bool pdEnable = false;
bool accelEnable = false;

/* USER CODE END PV */

void SystemClock_Config(void);
static void MX_GPIO_Init(void);
static void MX_I2C1_Init(void);
static void MX_ADC_Init(void);
/* USER CODE BEGIN 0 */

/**
 * @brief  Overwrite of the _write function. Outputs all calls to _write on the I2C bus to the DEBUG_TERMINAL address. Returns the length of the string to write.
 *
 * @param file: File descriptor of file into which data is written.
 * @param ptr: Pointer to data to be written.
 * @param len: Length in bytes of data to be written.
 * @retval int
 */
int _write(int file, char *ptr, int len)
{
  (void)file;
  int DataIdx;

  HAL_I2C_Master_Transmit(&hi2c1, DEBUG_TERMINAL, (uint8_t *) ptr, len, HAL_MAX_DELAY);
  return len;
}

// Only set to true, will print debug characters to an external debugger on i2c address DEBUG_TERMINAL. Otherwise does nothing.
#if DEBUG_TEST
/**
 * @brief  Writes a single given character to the DEBUG_TERMINAL through I2C.
 *
 * @param  out: The character to write
 * @retval None
 */
HAL_StatusTypeDef printDebugChar(uint8_t out) {
	HAL_I2C_Master_Transmit(&hi2c1, DEBUG_TERMINAL, &out, 1, HAL_MAX_DELAY);
}

/**
 * @brief  Writes a given character array of given size to the DEBUG_TERMINAL through I2C.
 *
 * @param  out: The character array to write
 * @param  size: The size of the character array
 * @retval None
 */
HAL_StatusTypeDef printDebug(uint8_t* out, int size) {
	HAL_I2C_Master_Transmit(&hi2c1, DEBUG_TERMINAL, out, size, HAL_MAX_DELAY);
}
#else

/**
 * @brief  Placeholder in case debug mode is disabled
 *
 * @param  out: The character to write. Ignored
 * @retval HAL_OK
 */
HAL_StatusTypeDef printDebugChar(uint8_t out) {
	return HAL_OK;
}

/**
 * @brief  Placeholder in case debug mode is disabled
 *
 * @param  out: The character to write. Ignored
 * @retval HAL_OK
 */
HAL_StatusTypeDef printDebug(uint8_t* out, int size) {
	return HAL_OK;
}
#endif

/**
 * @brief  Write a given amount of 0's to the NFC tag, starting from address 0.
 *
 * @param  size: Amount of 0's to write
 * @retval None
 */
void wipeMemory(int size) {
	for (uint16_t addr = 0; addr < size; addr++) {
		  HAL_I2C_Mem_Write(&hi2c1, NFC_ADDR, (uint16_t) addr, 2, &zero, 1, 1000);
	  	  HAL_Delay(10);
	  }
}

/**
 * @brief  Write a given array of bytes to the NFC tag, starting at a given memory address.
 *         Ensures that the NFC tag is done writing before returning.
 *
 * @param  data: Pointer to the byte array to be written
 * @param  size: The amount bytes to write
 * @param  memAddr: The memory-address of the first byte
 * @retval HAL_StatusTypeDef
 */
HAL_StatusTypeDef writeMemory(uint8_t* data, int size, uint16_t memAddr) {
	HAL_StatusTypeDef status = HAL_I2C_Mem_Write(&hi2c1, NFC_ADDR, memAddr, I2C_MEMADD_SIZE_16BIT, data, size, HAL_MAX_DELAY);
	HAL_Delay(2);

	uint8_t count = 0;
	while(HAL_I2C_IsDeviceReady(&hi2c1, NFC_ADDR, 1, 5) != HAL_OK && count < 50) {
		HAL_Delay(5);
		count++;
	}

	return status;
}

/**
 * @brief  Write a given array of bytes to the data section of the NFC tag.
 *         Automatically selects the end of the data section increments the memory pointer (locally, not on the NFC tag).
 *
 * @param  data: Pointer to the byte array to be written
 * @param  size: The amount of bytes to write
 * @retval HAL_StatusTypeDef
 */
HAL_StatusTypeDef writeDataMemory(uint8_t* data, int size) {
	if (memPointer + size >= MEMORY_SIZE || memPointer < 9) {
		return 1;
	}

	HAL_StatusTypeDef status = writeMemory(data, size, memPointer);
	memPointer += size;

	return status;
}

/**
 * @brief  Saves the local memory pointer to the NFC tag.
 *
 * @retval HAL_StatusTypeDef
 */
HAL_StatusTypeDef saveMemPointer() {
	if (memPointer >= 9 && memPointer <= MEMORY_SIZE) {
		uint8_t buff[2] = {memPointer, (memPointer >> 8)};
		return writeMemory(buff, 2, MEM_POINTER_REG);
	}

	return HAL_ERROR;

}

/**
 * @brief  Scans the I2C bus for devices. Writes all addresses that respond to the NFC tag.
 *
 * @retval 0
 */
int I2CDeviceScan() {
	uint8_t final_addr = 0;

	HAL_StatusTypeDef resNfc = HAL_I2C_IsDeviceReady(&hi2c1, NFC_ADDR, 3, 5);
	HAL_StatusTypeDef recRtc = HAL_I2C_IsDeviceReady(&hi2c1, AM1805_ADDR, 3, 5);
	HAL_StatusTypeDef resAccel = HAL_I2C_IsDeviceReady(&hi2c1, ACCEL_ADDR, 3, 5);

	for (uint8_t addr = 0; addr < 128; addr++) {
		  HAL_StatusTypeDef res = HAL_I2C_IsDeviceReady(&hi2c1, (uint16_t)(addr<<1), 3, 5);
		  if (res == HAL_OK) {
			  final_addr = (addr<<1);
			  HAL_I2C_Mem_Write(&hi2c1, NFC_ADDR, memPointer, 2, &final_addr, 1, 1000);
			  memPointer += 1;
		  }

		  HAL_Delay(10);
	  }

	  HAL_I2C_Mem_Write(&hi2c1, NFC_ADDR, memPointer, 2, &zero, 1, 1000);
	  memPointer += 1;

	  return 0;
}

/**
 * @brief  Enables all sensors that should be enabled
 *
 * @retval None
 */
void enableSensors() {
	if (accelEnable || tempEnable) {
		uint8_t enableAccel = 0b00010000; //low power mode, lowest frequency, 12 bit
		enableAccel = 0x3B;
		HAL_I2C_Mem_Write(&hi2c1, ACCEL_ADDR, ACCEL_CONTROL1, I2C_MEMADD_SIZE_8BIT, &enableAccel, 1, HAL_MAX_DELAY);
		enableAccel = 0x03;
		HAL_I2C_Mem_Write(&hi2c1, ACCEL_ADDR, 0x22, I2C_MEMADD_SIZE_8BIT, &enableAccel, 1, HAL_MAX_DELAY);
	} else {
		HAL_I2C_Mem_Write(&hi2c1, ACCEL_ADDR, ACCEL_CONTROL1, I2C_MEMADD_SIZE_8BIT, &zero, 1, HAL_MAX_DELAY);
	}

	if (pdEnable) {
		HAL_ADCEx_Calibration_Start(&hadc, ADC_SINGLE_ENDED);
	}

}

/**
 * @brief  Set the RTC to sleep for the given interval.
 *
 * @param  interval: The sleep interval in BCD. The first bit determines if the interval is in seconds (0) or minutes (1)
 * @retval None
 */
void initRtcSleep(uint8_t interval) {

	// Setup the RTC into alarm mode.
	uint8_t value = 0b10100001; // 0xA1
	HAL_I2C_Mem_Write(&hi2c1, AM1805_ADDR, RTC_CONFIGURATION_KEY, I2C_MEMADD_SIZE_8BIT, &value, 1, 100);

	value = rcEnable ? 0b10000100 : 0b00000100;
	 // 0x04 for XT -> changed to 0x84 for RC
	HAL_I2C_Mem_Write(&hi2c1, AM1805_ADDR, RTC_OSCILLATOR_CONTROL, I2C_MEMADD_SIZE_8BIT, &value, 1, 100);

	uint8_t timeReg;
	uint8_t alarmReg;

	bool minutesSelected = interval & 0b10000000;

	// Determine the alarm values that should be set.
	if (minutesSelected) {
		// Minutes interval
		timeReg = RTC_MINUTES;
		alarmReg = RTC_MINUTES_ALARM;
		value = bootMinutes;

	} else {
		// Seconds interval
		timeReg = RTC_SECONDS;
		alarmReg = RTC_SECONDS_ALARM;
		value = bootSeconds;

	}

	// Set the alarm value.
	if (value > 0x59) {
		HAL_I2C_Mem_Read(&hi2c1, AM1805_ADDR, timeReg, I2C_MEMADD_SIZE_8BIT, &value, 1, 100);
	}

	// Check if both value and interval are in BCD and are not out of bounds.
	if (((value & 0b11110000) >> 4) >= 6 || (value & 0b00001111) > 9) {
		value = 0x00;
	}
	if (((interval & 0b01110000) >> 4) >= 6 || (interval & 0b00001111) > 9) {
		interval = 0x00;
	}

	if (((value & 0b00001111) + (interval & 0b00001111)) > 9) value += 6; // If the ones overflow, increment by 6 to get back to actual value!
	value += (interval & 0b01111111);
	if (value > 0x59) value = value - 0x60; // Changed from setting to 0 to setting to decrementing by 0x59. This will keep functionality as expected!

	// Check if value is still BCD after calculation.
	if (((value & 0b11110000) >> 4) >= 6 || (value & 0b00001111) > 9) {
		value = 0x00;
	}

	// Set and enable alarm. Should turn off MCU.
	HAL_I2C_Mem_Write(&hi2c1, AM1805_ADDR, alarmReg, I2C_MEMADD_SIZE_8BIT, &value, 1, 100);

	value = 0b00111000; // 0x38
	HAL_I2C_Mem_Write(&hi2c1, AM1805_ADDR, RTC_CONTROL2, I2C_MEMADD_SIZE_8BIT, &value, 1, 100);

	value = 0b10000100; // 0x84
	HAL_I2C_Mem_Write(&hi2c1, AM1805_ADDR, RTC_INTMASK, I2C_MEMADD_SIZE_8BIT, &value, 1, 100);

	value = minutesSelected ? 0b00010111 : 0b00011011; // 0x1B
	HAL_I2C_Mem_Write(&hi2c1, AM1805_ADDR, RTC_COUNTDOWN_TIMER_CONTROL, I2C_MEMADD_SIZE_8BIT, &value, 1, 100);

	value = 0;
	HAL_I2C_Mem_Write(&hi2c1, AM1805_ADDR, RTC_STATUS, I2C_MEMADD_SIZE_8BIT, &value, 1, 100);

	value = 0b10000000; // 0x80
	HAL_I2C_Mem_Write(&hi2c1, AM1805_ADDR, RTC_SLEEP_CONTROL, I2C_MEMADD_SIZE_8BIT, &value, 1, 100);
}

/**
 * @brief  Tries to trigger a sleep on the RTC for the given interval. If it fails 10 times, resets the MCU.
 *
 * @retval None
 */
void rtcSleep(uint8_t interval, bool saveMP) {
	// Only save memory pointer when requested. Default is false.
	if (saveMP) {
		saveMemPointer();
	}


	uint8_t stop_count = 0;

	// Try to stop the MCU through the RTC 10 times.
	while (stop_count < 10) {
		initRtcSleep(interval);
		HAL_Delay(50);
		stop_count++;
	}

	// If stopping through the RTC failed, reset the MCU.
	NVIC_SystemReset();
}

/* USER CODE END 0 */

/**
  * @brief  The application entry point.
  * @retval int
  */
int main(void)
{
  /* MCU Configuration--------------------------------------------------------*/

  /* Reset of all peripherals, Initializes the Flash interface and the Systick. */
  HAL_Init();

  /* Configure the system clock */
  SystemClock_Config();

  /* Initialize all configured peripherals */
  MX_GPIO_Init();
  MX_I2C1_Init();
  MX_ADC_Init();
  /* USER CODE BEGIN 2 */

//  I2CDeviceScan();
  // Wait for the RTC to start. Necessary when this is the first time the entire systems starts.
  HAL_Delay(5);

  // Retrieve RTC seconds and minutes at boot.
  HAL_StatusTypeDef status = HAL_I2C_Mem_Read(&hi2c1, AM1805_ADDR, RTC_SECONDS, I2C_MEMADD_SIZE_8BIT, &bootSeconds, 1, 100);
  status = HAL_I2C_Mem_Read(&hi2c1, AM1805_ADDR, RTC_MINUTES, I2C_MEMADD_SIZE_8BIT, &bootMinutes, 1, 100);

  // Check the first two bytes of the timestamp. If < 3400, retrieve VDDA, store it in the first two ts bytes and rtcSleep for 5 seconds.
#if CHARGE_MODE
  uint8_t ts_buff[2] = {};
  status = HAL_I2C_Mem_Read(&hi2c1, NFC_ADDR, TIMESTAMP_REG, I2C_MEMADD_SIZE_16BIT, ts_buff, 2, HAL_MAX_DELAY);
  uint16_t timestamp  = ((uint32_t) ts_buff[0] << 8) | ts_buff[1];

  if (timestamp < 3400) {
	  HAL_ADCEx_Calibration_Start(&hadc, ADC_SINGLE_ENDED);

	  HAL_ADC_Start(&hadc);
	  HAL_ADC_PollForConversion(&hadc, HAL_MAX_DELAY);
	  HAL_ADC_GetValue(&hadc);

	  HAL_ADC_Start(&hadc);
	  HAL_ADC_PollForConversion(&hadc, HAL_MAX_DELAY);
	  uint32_t vrefMeasured = HAL_ADC_GetValue(&hadc);
	  uint32_t vdda = VREF_CAL_VDDA * (*VREF_CAL_ADDR) / vrefMeasured; // VDDA * 1000

	  uint8_t vdda_buff[2] = {};
	  vdda_buff[0] = ((vdda & 0x0000ff00) >> 8);
	  vdda_buff[1] = (vdda & 0x000000ff);
	  if (status == HAL_OK) {
		  HAL_I2C_Mem_Write(&hi2c1, NFC_ADDR, (uint16_t) TIMESTAMP_REG, I2C_MEMADD_SIZE_16BIT, vdda_buff, 2, 1000);
		  HAL_Delay(10);
	  }

	  rtcSleep(0x05, false);
  }
#endif

  // Retrieve settings from the NFC tag. Break sensor enable byte into separate booleans.
  uint8_t sensorEnable = 0b10000000; // <0:IX, 1:RC>0<temperature><moisture><pd_en>00<accel_en>.

  if (DEBUG_TEST) {
	  sensorEnable = 0b00101111;
	  rtcInterval = 0x10;
  } else {
	  HAL_StatusTypeDef status =  HAL_I2C_Mem_Read(&hi2c1, NFC_ADDR, SENSOR_ENABLE_REG, I2C_MEMADD_SIZE_16BIT, &sensorEnable, 1, HAL_MAX_DELAY);
	  HAL_I2C_Mem_Read(&hi2c1, NFC_ADDR, RTC_INTERVAL_REG, I2C_MEMADD_SIZE_16BIT, &rtcInterval, 1, HAL_MAX_DELAY);
	  HAL_I2C_Mem_Read(&hi2c1, NFC_ADDR, STARTUP_DELAY_REG, I2C_MEMADD_SIZE_16BIT, &startupDelay, 1, HAL_MAX_DELAY);

	  uint8_t buff[2] = {} ;
	  HAL_I2C_Mem_Read(&hi2c1, NFC_ADDR, MEM_POINTER_REG, I2C_MEMADD_SIZE_16BIT, buff, 2, HAL_MAX_DELAY);

	  memPointer = buff[0] | ((uint16_t) buff[1] << 8);
  }

  if (startupDelay & 0b10000000) {
	  uint8_t newStartupDelay = startupDelay & 0b01111111;
	  writeMemory(&newStartupDelay, 1, STARTUP_DELAY_REG);
	  rtcSleep(startupDelay, false);
  }

  // Conversion to bool, False if 0, True otherwise.
  rcEnable = sensorEnable 	 & 0b10000000; // 0 means RTC on XT oscillator. 1 means RTC on RC oscillator.
  tempEnable = sensorEnable 	 & 0b00100000;
  if ((sensorEnable & 0b00010110)) {
	  sensorEnable = sensorEnable & 0b11101001;
	  writeMemory(&sensorEnable, 1, SENSOR_ENABLE_REG);
  }
  pdEnable = sensorEnable 		 & 0b00001000;
  accelEnable = sensorEnable 	 & 0b00000001;

  // Enable sensors that are turned on in enable sensor register.
  enableSensors();
  HAL_Delay(5);

  uint8_t inputPointer = 0;
  uint8_t inputBuffer[22] = {};

  /* USER CODE END 2 */

  /* Infinite loop */
  /* USER CODE BEGIN WHILE */

  // Read all sensors that are turned on and store the values in a buffer.
  if (tempEnable) {
	  HAL_I2C_Mem_Read(&hi2c1, (uint16_t) ACCEL_ADDR, ACCEL_TEMP_BASE, I2C_MEMADD_SIZE_8BIT, inputBuffer, 2, HAL_MAX_DELAY);
	  inputPointer += 2;
  } else if (pdEnable) {
	  // Add an extra byte to the buffer in case the temperature is not enabled, but pd is. Byte is later used to store VDDA.
	  inputBuffer[0] = 0;
	  inputPointer += 1;
  }

  if (pdEnable) {
	  // Skip first value
	  HAL_ADC_Start(&hadc);
	  HAL_ADC_PollForConversion(&hadc, HAL_MAX_DELAY);
	  HAL_ADC_GetValue(&hadc);
	  HAL_ADC_Start(&hadc);
	  HAL_ADC_PollForConversion(&hadc, HAL_MAX_DELAY);
	  HAL_ADC_GetValue(&hadc);

	  HAL_ADC_Start(&hadc);
	  HAL_ADC_PollForConversion(&hadc, HAL_MAX_DELAY);
	  uint32_t pdValue = HAL_ADC_GetValue(&hadc);
	  // To calibrate: pdValue = ((pdValue * vdda) / 4095) / 1000;
	  inputBuffer[inputPointer] = pdValue;
	  inputBuffer[inputPointer+1] = (pdValue >> 8) & 0x0F;
	  inputPointer += 2;

  }

  // If temperature and/or photodiode is enabled, retrieve VDDA.
  if (tempEnable || pdEnable) {
	  if (!pdEnable) {
		  HAL_ADC_Start(&hadc);
		  HAL_ADC_PollForConversion(&hadc, HAL_MAX_DELAY);
		  HAL_ADC_GetValue(&hadc);
	  }

	  HAL_ADC_Start(&hadc);
	  HAL_ADC_PollForConversion(&hadc, HAL_MAX_DELAY);
	  uint32_t vrefMeasured = HAL_ADC_GetValue(&hadc);
	  uint32_t vdda = VREF_CAL_VDDA * (*VREF_CAL_ADDR) / vrefMeasured; // VDDA * 1000
	  vdda = (vdda / 100); //VDDA * 10 -> [18,33] mapped to [0, 15]. Also takes 0.1V difference into account with reality into account
	  vdda = (vdda > 33) ? 33 : vdda;
	  vdda = (vdda < 18) ? 18 : vdda;
	  vdda -= 18;
	  inputBuffer[0] = inputBuffer[0] | (vdda & 0x0F);
  }

  if (accelEnable) {
	  HAL_I2C_Mem_Read(&hi2c1, (uint16_t) ACCEL_ADDR, ACCEL_OUT_X_L, I2C_MEMADD_SIZE_8BIT, inputBuffer + inputPointer, 6, HAL_MAX_DELAY);
	  inputPointer += 6;
  }

  // Write sensor values to NFC tag. Then enter RTC sleep with interval set in settings.
  writeDataMemory(inputBuffer, inputPointer);
  rtcSleep(rtcInterval, true);
    /* USER CODE END WHILE */

}

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
/* USER CODE BEGIN 4 */

//int __io_putchar(int ch) {
//	ITM_SendChar(ch);
//
//	return ch;
//}

/* USER CODE END 4 */
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


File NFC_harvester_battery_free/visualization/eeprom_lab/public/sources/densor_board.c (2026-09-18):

#include "main.h"
#include "densor_board.h"
#include "densor_r1.h"
#include "tmp119.h"
#ifdef DENSOR_MULTIRATE
#include "densor_multirate.h"
#include "densor_logger.h"
#include "densor_scheduler.h"
#endif
#include <string.h>

extern ADC_HandleTypeDef hadc;
extern I2C_HandleTypeDef hi2c1;
enum { NFC = 0xa6, NFC_SYSTEM = 0xae, LIS = 0x32, DENSOR_RTC_ADDR = 0xd2, TMP = 0x90,
       BUS_TIMEOUT_MS = 25 };
#ifdef DENSOR_MULTIRATE
static mr_session session;
static uint32_t boot_time;
#else
static densor_session session;
#endif
static bool session_loaded;
static bool memory_write_failed;
static uint8_t boot_seconds, boot_minutes;
volatile uint32_t densor_provision_request;

/* The provisioning helper breaks HERE, after C initialization, and sets the
 * request through SWD. Normal firmware cannot format an unknown/legacy tag. */
__attribute__((noinline)) void densor_boot_gate(void) { __asm volatile ("nop" ::: "memory"); }
static bool read_reg(uint16_t dev, uint16_t reg, uint16_t width, uint8_t *p, uint16_t n) {
    return HAL_I2C_Mem_Read(&hi2c1, dev, reg, width, p, n, BUS_TIMEOUT_MS) == HAL_OK;
}
static bool write_reg(uint16_t dev, uint16_t reg, uint16_t width, const uint8_t *p, uint16_t n) {
    return HAL_I2C_Mem_Write(&hi2c1, dev, reg, width, (uint8_t *)p, n, BUS_TIMEOUT_MS) == HAL_OK;
}
static bool read_memory(uint16_t a, uint8_t *p, uint16_t n) { return read_reg(NFC, a, I2C_MEMADD_SIZE_16BIT, p, n); }
static bool write_memory(uint16_t a, const uint8_t *p, uint16_t n) {
    bool ok = write_reg(NFC, a, I2C_MEMADD_SIZE_16BIT, p, n);
    if (!ok) memory_write_failed = true;
    return ok;
}
static bool memory_ready(void) {
    for (unsigned attempt = 0; attempt < 12; ++attempt) {
        if (HAL_I2C_IsDeviceReady(&hi2c1, NFC, 1, 2) == HAL_OK) return true;
        HAL_Delay(1);
    }
    memory_write_failed = true;
    return false;
}
static const densor_io memory = { read_memory, write_memory, memory_ready };
static uint8_t tmp_read(uint8_t reg, uint16_t *value) {
    uint8_t p[2];
    if (!read_reg(TMP, reg, I2C_MEMADD_SIZE_8BIT, p, 2))
        return HAL_I2C_GetError(&hi2c1) == HAL_I2C_ERROR_AF ? DENSOR_SENSOR : DENSOR_IO;
    *value = (uint16_t)(((uint16_t)p[0] << 8) | p[1]);
    return DENSOR_OK;
}
static uint8_t tmp_write(uint8_t reg, uint16_t value) {
    uint8_t p[2] = {(uint8_t)(value >> 8), (uint8_t)value};
    return write_reg(TMP, reg, I2C_MEMADD_SIZE_8BIT, p, 2) ? DENSOR_OK : DENSOR_IO;
}
static const tmp119_bus temperature = { tmp_read, tmp_write, HAL_GetTick, HAL_Delay };
static bool rtc_write(uint8_t reg, uint8_t value) { return write_reg(DENSOR_RTC_ADDR, reg, I2C_MEMADD_SIZE_8BIT, &value, 1); }
#ifndef DENSOR_MULTIRATE
static bool bcd_valid(uint8_t b) { return (b & 15) <= 9 && (b >> 4) <= 5; }
#endif
static uint8_t bcd_decode(uint8_t b) { return (uint8_t)((b >> 4) * 10 + (b & 15)); }
static uint8_t bcd_encode(unsigned b) { return (uint8_t)(((b / 10) << 4) | (b % 10)); }
#ifdef DENSOR_MULTIRATE
/* AM18X5 §5.5: one burst latches calendar counters. No hundredths in RC mode. */
static bool rtc_calendar(uint32_t *seconds) {
    uint8_t b[6], control;
    static const uint8_t days_in_month[12]={31,28,31,30,31,30,31,31,30,31,30,31};
    if (!read_reg(DENSOR_RTC_ADDR,0x10,1,&control,1) || (control&0xc0)
        || !read_reg(DENSOR_RTC_ADDR,1,1,b,6)) return false;
    b[0]&=0x7f; b[1]&=0x7f; b[2]&=0x3f; b[3]&=0x3f; b[4]&=0x1f;
    unsigned v[6];
    for (unsigned i=0;i<6;++i) {
        if ((b[i]&15)>9 || (b[i]>>4)>9) return false;
        v[i]=bcd_decode(b[i]);
    }
    unsigned y=v[5], m=v[4], d=v[3];
    if (v[0]>59 || v[1]>59 || v[2]>23 || !m || m>12 || !d
        || d>days_in_month[m-1]+(unsigned)(m==2 && y%4==0)) return false;
    uint32_t days=365u*y+(y+3)/4+d-1;
    for (unsigned i=1;i<m;++i) days+=days_in_month[i-1]+(unsigned)(i==2 && y%4==0);
    *seconds=((days*24+v[2])*60+v[1])*60+v[0];
    boot_seconds=b[0]; boot_minutes=b[1]; return true;
}
static bool ram_bank(void) {
    uint8_t v;
    return read_reg(DENSOR_RTC_ADDR,0x3f,1,&v,1) && rtc_write(0x3f,v&0xfcu);
}
static bool ram_read(uint16_t a, uint8_t *p, uint16_t n) {
    return a+n<=64 && ram_bank() && read_reg(DENSOR_RTC_ADDR,0x40+a,1,p,n);
}
static bool ram_write(uint16_t a, const uint8_t *p, uint16_t n) {
    bool ok=a+n<=64 && ram_bank() && write_reg(DENSOR_RTC_ADDR,0x40+a,1,p,n);
    if (!ok) memory_write_failed=true;
    return ok;
}
static const mr_ram retained={ram_read,ram_write,rtc_calendar};
static bool rtc_read_boot(void) { return rtc_calendar(&boot_time); }
#else
static bool rtc_read_boot(void) {
    for (unsigned n = 0; n < 3; ++n) {
        uint8_t time[2], seconds;
        if (!read_reg(DENSOR_RTC_ADDR, 1, 1, time, 2) || !read_reg(DENSOR_RTC_ADDR, 1, 1, &seconds, 1)) return false;
        if (seconds == time[0] && bcd_valid(seconds) && bcd_valid(time[1])) {
            boot_seconds = time[0]; boot_minutes = time[1]; return true;
        }
    }
    return false;
}
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

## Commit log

2026-09-18 Hardware implementation
    [board-1.6mm.step, bom.csv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]
2026-09-18 Implement firmware R1 with temp logging and Android support -
    - Add independent LIS2DW12/TMP119 temperature selection, preserving signed readings and separate supply-voltage data.
    - Align records to four-byte EEPROM pages and split writes at page boundaries.
    - Use bounded ACK polling to confirm programming before advancing the log pointer; halt on uncertain write completion.
    - Detect EEPROM capacity at runtime, validate record bounds, and stop acquisition when memory is full.
    - Add CRC-checked configuration metadata and settings/reset requests, applied on regular wakes with an optional startup delay.
    - Add bounded sensor timeouts and explicit acquisition/error handling.
    - Update Android con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
    [build-results.csv, record-fixtures.csv, run-results.csv]
2026-09-18 Implement R2 shared and R3 partitioned multirate sampling
    Select retained FSM scheduling with suffix a and RTC timer scheduling with
    suffix b. Calculate fixed session allocations in Android and support R1
    alongside both multirate storage families.
    Use one multirate EEPROM layout, smart partition padding and whole-page shared
    records. Include firmware, host and phone regression coverage.
    [DensorPhoneTest.java]
2026-09-18 Added visualization tools
    [events.csv, ground_truth.csv, samples.csv]
